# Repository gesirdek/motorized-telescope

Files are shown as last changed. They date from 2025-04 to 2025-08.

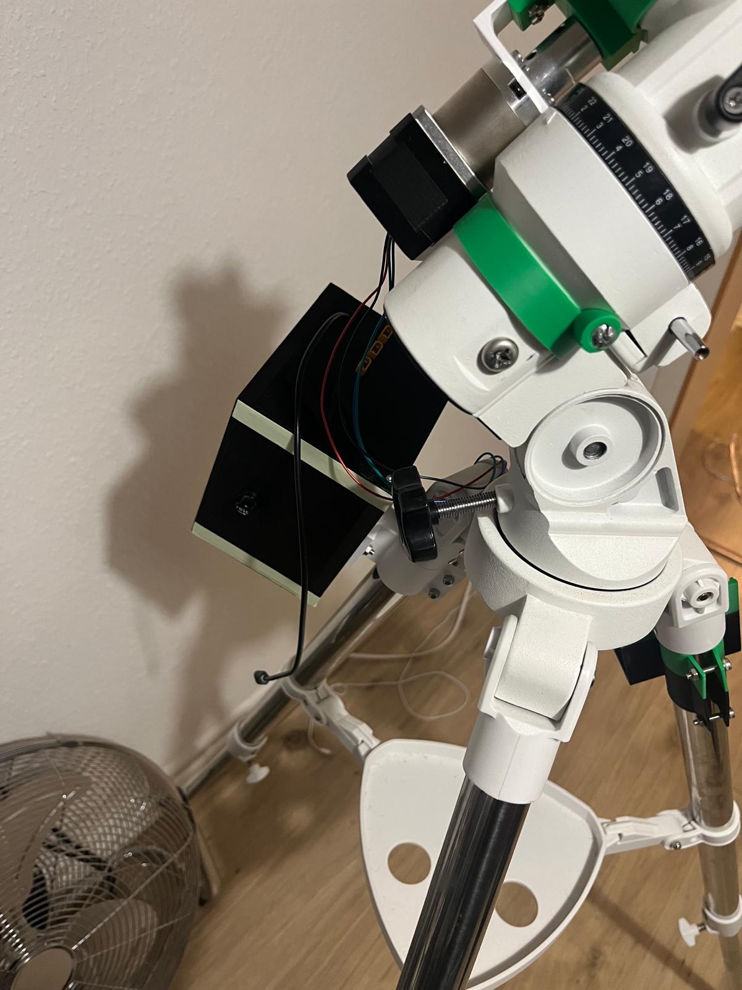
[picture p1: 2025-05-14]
photos/power-box-assembled.jpeg

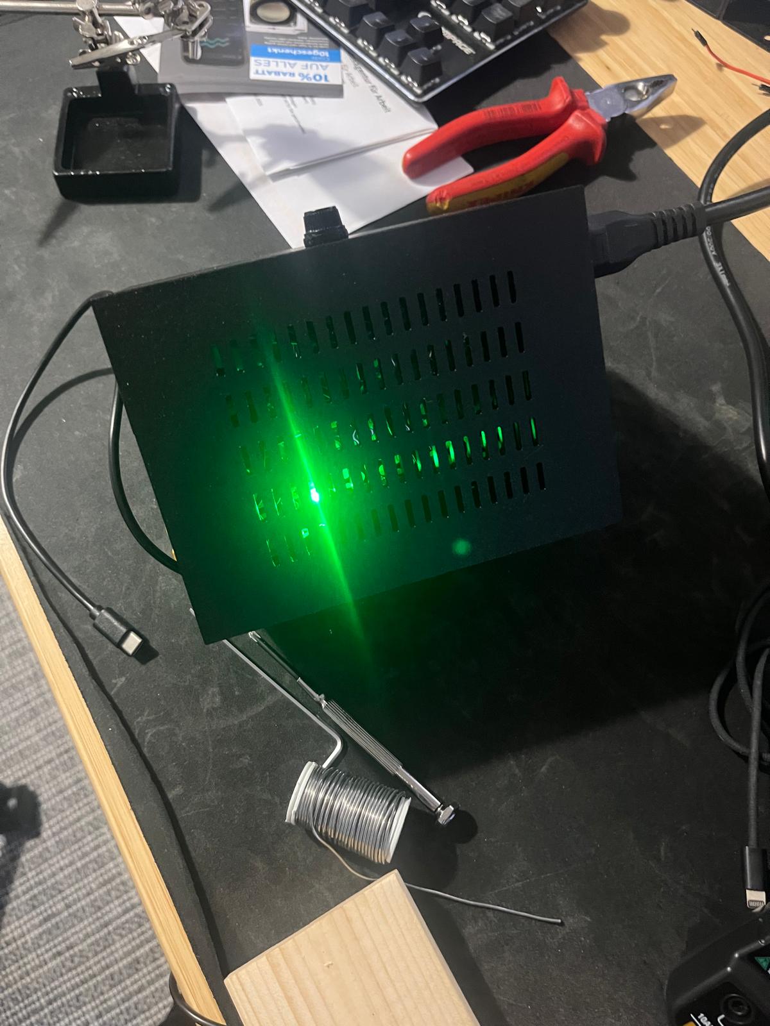
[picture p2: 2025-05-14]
photos/power-box-assembled-2.jpeg

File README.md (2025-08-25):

# Motorized Telescope

A fully motorized telescope project using 3D-printed parts, FreeCAD modeling, and ROS-based control system.  
The telescope uses an equatorial mount (Bresser AR102/1000) and will be upgraded with motors on the **Right Ascension (RA)**, **Declination (DEC)**, and **Focuser** axes for automatic tracking, alignment, and remote focusing.

This repository documents the full development process, including CAD models, electronics, motor control, ROS integration, and testing.

---

## 🚀 Project Goals

- ✅ Motorize **RA**, **DEC** axes using NEMA 17 planetary gear stepper motors.
- ✅ Motorize **Focuser** using 28BYJ-48 stepper motor.
- ✅ Design all mechanical parts in **FreeCAD** and prototype them with a **3D printer**.
- ✅ Control the motors via **stepper drivers (A4988 → TMC2209, ULN 2003)** and a **microcontroller (Arduino → D1 Mini)**.
- ✅ Use **ROS** for high-level control and coordination.
- ✅ Implement **GoTo & Tracking** based on celestial coordinates.
- ✅ Document all failed and revised prototypes to reduce material waste and improve design efficiency.
- ✅ Switched to **Raspberry Pi** for portable, self-contained operation.
- 🕒 Future plan - Support solar-powered operation for outdoor autonomy.

---

## ⚙️ Hardware Overview

| Component | Description |
|---|---|
| Telescope | Bresser AR102/1000, Equatorial Mount |
| Motors | NEMA 17 with Planetary Gear, 28BYJ-48 Step Motor  |
| Motor Drivers | NEMA 17 - A4988 (initial) → TMC2209 (planned), 28BYJ-48 - ULN 2003 |
| Microcontroller | D1 Mini (ESP8266) |
| Host Controller | Raspberry Pi 3 Model B+ |
| Power Supply | 12V 5A USB Adapter (later: solar panel) |
| 3D Printer | Bambu Lab P1P |

## 🛠️ Current Status

- [x] Repository initialized and documented
- [x] CAD measurements started, prototype V1 tested
- [x] Final RA motor mount design in progress
- [x] DEC mount modeling
- [x] Focuser gear mechanism prototyping
- [ ] ROS communication layer setup
- [ ] Integrated system test

---

## 📸 Photos & Prototyping Log

🗂️ Detailed iteration logs and photos are available in  
👉 [prototype-log.md](prototype-log.md)

## 📂 Repository Structure (Simplified)

- `cad/` → FreeCAD source file and STL files for 3D printing, and Bambu Studio `.3mf` project files
- `photos/` → Images of prototypes, failed prints, and final assemblies  
- `pcb/` → Gerber files and PCB resources for the motor control board
- `arduino/` → Microcontroller firmware for stepper drivers  
- `ros/` → ROS nodes for telescope control logic  
- `prototype-log.md` → Iteration notes, measurements, and learning from each step

## 📐 CAD Files

- All mechanical parts are designed in individual FreeCAD files.

- Each functional group (e.g. RA/DEC parts, power box) lives in its own folder under `/cad/`.

- Discarded or outdated parts are moved to a central file: [`TelescopeProject.FCStd`](cad/TelescopeProject.FCStd)

- Bodies that are no longer in use are marked with the suffix `_discarded`.  
  These represent either failed prints or designs that were intentionally replaced with better alternatives.

- STL files in `/cad/stl/` are **cleaned and curated**: they represent only the **most up-to-date and usable** versions of each part. 
- STL files in `/cad/stl/` follow the **same folder structure** as the FreeCAD source files.
- Discarded or outdated versions (which may have been printed previously) are **not included here**, but still exist as separate bodies in the FreeCAD source file

<details>
<summary>📁 CAD Folder Structure (click to expand)</summary>

```
/cad/
├── telescope_body_parts/
│ ├── DEC-Half-Pipe.FCStd
│ └── RA-Half-Pipe.FCStd
├── power-box-parts/
│ ├── Pin.FCStd
│ ├── Power-Box-Back.FCStd
│ ├── Power-Box-Base.FCStd
│ ├── Power-Box-Front.FCStd
│ ├── Power-Box-Left-Side.FCStd
│ ├── Power-Box-Right-Side.FCStd
│ └── Power-Box-Top.FCStd
├── ec-box-parts/
│ ├── EC-base.FCStd
│ ├── EC-Box-Assembly.FCStd
│ ├── EC-Box-Side-L.FCStd
│ ├── EC-Box-Side-R.FCStd
│ └── EC-Box-Top.FCStd
├── shared_parts/
│ ├──  L-Grabber.FCStd
│ └── TripodGrabber.FCStd
├── crayford_focuser/
│ ├── bearings-base.FCStd
│ ├── crayford-focuser-presser.FCStd
│ ├── crayford-holder.FCStd
│ └── crayford-tube.FCStd
├── stl/
│ ├── telescope_body_parts/
│ ├── power-box-parts/
│ ├── ec-box-parts/
│ ├── crayford_focuser/
│ └── shared_parts/
└── TelescopeProject.FCStd
```
</details>

## 🎛️ Bambu Studio Project Files

The `bambu-studio/` folder contains `.3mf` project files created with Bambu Studio. These files include both the 3D model(s) and all relevant print settings (such as layer height, speed, support configuration, and filament type) used for slicing.

Unlike some other slicers, Bambu Studio does not store print settings as separate configuration files — all settings are embedded within the `.3mf` file itself.

### Notes
- File names may indicate specific profiles (e.g., "high-quality", "draft", or nozzle size), but the actual configuration is always included in the `.3mf` file.
- If you're using a different slicer or printer, refer to the `.stl` files in the `stl/` folder and manually adjust your settings based on the intended configuration.
- Optional: some setting screenshots may also be included for reference.

## 🧩 PCB Files

Initial Gerber files for the motor control board are provided under `/pcb/gerber-files/`.

These are **v1 design files** and **have not yet been sent for PCB manufacturing**.  
Future versions may include design improvements based on testing results.

## ⚡ Power Supply Setup

The power supply consists of a ready-made 12V 5A unit mounted inside a protective enclosure.  
An inline T1A fuse (slow-blow) is installed on the AC input for safety, and a DC power distributor with integrated fuses is used to organize the 12V outputs.

No custom PCB is created for the power supply; connections are made manually using standard wiring.

## ⚠️ Disclaimer

This project involves work with high voltages (230V AC) and is provided as-is without any warranty.  
Use at your own risk. Ensure you have proper knowledge and take appropriate safety measures when replicating or modifying this system.

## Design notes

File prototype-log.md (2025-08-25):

# Prototyping & Iteration Log

This document records all 3D printed prototypes, their testing results, and learnings. Even failed or broken parts are documented to highlight design evolution and material efficiency.

---

## 📅 April 2025 — RA Half Pipe (First Attempt)

- **Goal**: Design a half-pipe mount to secure motor housing around the RA axis.
- **Result**: The piece cracked near the bolt hole. Instead of increasing wall thickness, I decided to extend the length of the half-circle so that the mounting holes would be easier to align and allow M5 screws to fit without stress.
- **Learning**: Geometric adjustments (e.g., part length) can sometimes be more effective than increasing thickness. This change also helped with assembly tolerance.
- 📸 `photos/RA-half-pipe-end-fail.jpeg`

---

## 📅 April 2025 — DEC Half Pipe (First Version)

- **Goal**: Create a symmetrical half-pipe bracket for the DEC axis mount.
- **Result**: Initial design printed correctly but cracked under bolt pressure.
- **Fix**: Strengthened the model with wider edge and offset the holes from edge.
- 📸 `photos/DEC-half-pipe-first-version.jpeg`
- 📸 `photos/DEC-Half-pipe-crack.jpeg`

---

## 📅 April 2025 — L-Bracket Motor Mounts (Comparison)

- **Goal**: Compare and test two L-bracket versions for mounting the NEMA17 planetary gear motor.
- **Result**: Both versions had compatible hole positions. However, the **left version was narrower**, which allowed correct positioning. The wider one did not leave enough clearance for the desired alignment.
- **Learning**: Bracket width matters for motor and coupling orientation — even if hole alignment is correct.
- 📸 `photos/nema17-L-bracket-2-versions-left-fits.jpeg`

---

## 📅 April 2025 — DEC Motor Mount (Mechanical Assembly Test)

- **Goal**: Assemble the DEC motor mount using the latest half-pipe version and L-bracket to test mechanical alignment and fit.
- **Result**: Mounting was mechanically successful. The motor aligned well with the coupling, and the bracket provided stable support. However, the DEC half-pipe still needs visual and geometric refinement for better fit and finish.
- **Next**: Perform motor test (rotation + holding torque) before proceeding to final cabling and driver installation.
- 📸 `photos/DEC-mount-succes-motor-L-connect.jpeg`
- 📸 `photos/DEC-mount-success-up.jpeg`
- 📸 `photos/DEC-coupling-motor-success.jpeg`

## 📅 April — RA Half Pipe V2 (Screw Alignment Issue)

- **Goal**: Redesign the RA half-pipe with a longer arc and improved screw hole alignment for M8 bolts.
- **Result**: The arc length was sufficient, but the screw hole geometry still didn't align properly with the mount holes. The piece couldn’t be mounted without excessive force.
- **Learning**: In the next version, precise measurement around the telescope collar and bolt spacing is required. Hole offset needs to be based on actual curvature path, not just diameter.
- 📸 `photos/RA-half-pipe-v2-failed-to-fit screw-2025-04-12 at 20.13.03.jpeg`

## 📅 April — RA Half-Pipe Adjustment Planning
- Slight increase in arc length (~3–5°) is required for better alignment of the motor arm.
- The M8 bolt hole needs a flared or curved entry for easier fitment, and slight sanding might be needed where the bracket meets the telescope.
- 📸 `photos/RA-half-pipe-adjustments-requıired-pipe-length.jpeg`, 
- 📸 `photos/RA-half-pipe-adjustments-requıired-screw.jpeg`

## 📅 April — RA Half Pipe Stable Version
- **Goal**: Produce a structurally stable RA half-pipe mount to carry the stepper motor.
- **Result**: The latest printed version successfully holds the motor with sufficient stability. Minor alignment refinements may still be required.
- 📸 `photos/14-04-2025-RA-half-pipe-stable_1.jpeg`,
- 📸 `photos/14-04-2025-RA-half-pipe-stable_2.jpeg`

## 📅 April — Updated L-Grabbers and Half-Pipe Mounts Installed
- **Goal**: Update L-grabbers and produce/install new half-pipe mounts for both RA and DEC motor setups.
- **Result**:Updated L-grabbers were successfully installed with revised half-pipe designs. Mounting alignment achieved with solid mechanical fit.
- 📸 `photos/L-Grabber-mounted-1.jpeg`,
- 📸 `photos/L-Grabber-mounted-2.jpeg`,
- 📸 `photos/L-Grabber-mounted-3.jpeg`

## 📅 April — First Motor Spin with D1 Mini
- **Goal**:  Verify stepper motor movement using D1 Mini and initial breadboarded electronics.
- **Result**: Successfully controlled one stepper motor via D1 Mini using STEP/DIR pins. Stable rotation achieved.
- 📸 `photos/Stepper-Motor-1.jpeg`,
- 📸 `photos/Stepper-Motor-E.jpeg`,
- 📸 `photos/Elect-Stepper-Motor.png`

## 📅 April 24, 2025 — Electronics Enclosure Design Started
- **Goal**: Begin designing a housing/enclosure for the electronics, including the D1 Mini and driver boards.
- **Result**:  Initial sketches and measurements completed. Enclosure will accommodate future upgrades. Next goal: drive two motors via a single D1 Mini.
- 📸 `photos/Elect-Box-1.png`
- 📸 `photos/Elect-Box-2.png`

## 📅 May 6, 2025 — Power Supply Enclosure Design in Progress
- **Goal**: Create a stable and compact enclosure to house the power supply and related wiring.
- **Result**:  Preliminary design completed in FreeCAD. Dimensions adjusted to fit under telescope tripod. Ventilation and cable routing considered.
- 📸 `photos/PETG-power-supply-fail.png`
- 📸 `photos/PETG-power-supply-fail-2.png`

## 📅 May 8, 2025 — Power Box Assembly Test (Right, Rear, Base)
- **Goal**: Print and test-fit the right, rear, and base parts of the power supply box.
- **Result**: Parts interlocked successfully. Some minor issues occurred.
- 📝 Forgot to include one of the holes on the rear panel — drilled manually.
- 📝 The lower interlock on the right side was printed with support; removal left a rough surface.
- 📝 Didn't sand the surface; assembly required some force but was possible.
- 📝 Fit was not smooth; alternative support strategy needed for future prints.
- 📸 `photos/power-box-fit-test-2025-05-08.png`
- 📸 `photos/power-box-back.jpeg`
- 📸 `photos/power-box-base-back-right.jpeg`
- 📸 `photos/power-box-right-panel.jpeg`

## 📅 May 14, 2025 — Power Box Final Assembly and Verification
- **Goal**: Complete assembly of the power supply box and perform final verification.
- **Result**: Assembly completed successfully. Output stable under load.
- 📝 All panels fully assembled and interlocked.
- 📝 Fluorescent tape applied to edges for visibility in low light.
- 📝 Hot glue used to secure internal components.
- 📝 Output voltage and current tested — stable operation confirmed.
- 📝 No overheating or noise detected during test.
- 📸 photos/power-box-assembled.jpeg
- 📸 photos/power-box-assembled-2.jpeg
- 📸 photos/power-box-internal-hotglue.jpeg
- 📸 photos/power-box-fluorescent-edges.jpeg

## 📅 May 21, 2025 — RA/DEC Motor Box Assembly and Test
- **Goal**: Assemble the RA/DEC control box, wire the electronics, and verify functionality via MQTT.
- **Result**: System operational; motors respond correctly to MQTT commands.
- 📝 RA/DEC box assembled and electronics placed inside.
- 📝 All internal wiring completed; connections verified.
- 📝 One faulty Dupont cable was replaced.
- 📝 Box closed and system tested.
- 📝 After powering D1 Mini and sending MQTT command via Mosquitto, both RA and DEC motors moved as expected.
- 📝 Noticed that motor power must be connected after D1 Mini is powered on — this behavior needs investigation.
- 📝 Planned task completed: Structured Wi-Fi command interface implemented using MQTT; remote control now functional.
- 📽️ [Watch test video on YouTube](https://youtube.com/shorts/sel-l1Y8c-Y)

## 📅 May 21, 2025 — Motor Power Sequencing Issue: Solution Identified
- **Goal**: Investigate why motors must be powered only after D1 Mini boot.
- **Result**: Root cause identified; hardware solution planned but not yet implemented.
- 📝 Observed issue: system only works if motor power is connected after D1 Mini is booted.
- 📝 Suspected power sequencing conflict between D1 Mini and motor drivers.
- 📝 Proposed solution: add IRLZ44N N-channel MOSFET to control motor GND via GPIO.
- 📝 D1 Mini would enable motor power after it completes boot sequence.
- 📝 330Ω resistor and optional 10kΩ pull-down recommended for stable gate control.
- 📝 Implementation pending — to be tested in upcoming iteration.
- 📝 Gerber files will need to be updated if solution is verified.

## 📅 June 08, 2025 — Crayford Focuser Design Initiated
- **Goal**: Begin designing a Crayford-style focuser with stepper motor integration.
- **Result**: Initial design concepts completed; parts adapted to motor and shaft geometry.
- 📝 Started working on focuser motor design; aiming to build a Crayford focuser.
- 📝 Creating a design that allows mounting a 28BYJ-48 stepper motor.
- 📝 Planning to reuse a shaft from an old toy car wheel as the drive axle.
- 📝 Updated current designs to accommodate the reused shaft.

## 📅 June 20, 2025 — Crayford Focuser Mechanism Assembled and Tested
- **Goal**: Complete physical assembly of the Crayford focuser and verify mechanical operation.
- **Result**: Assembly completed successfully; mechanical movement confirmed; initial driver circuit test passed.
- 📝 Crayford focuser mechanism fully assembled and manually tested.
- 📝 Basic physical operation appears normal; no major resistance or misalignment observed.
- 📝 This test only covered manual operation, motor-driven behavior on the focuser itself still untested.
- 📝 Switched to a metal coupling for the drive axle, which improved mechanical consistency and alignment.
- 📝 Stepper motor and driver circuit tested separately — motor responds correctly.

## 📅 August 20, 2025 — Crayford Focuser Motor Test & MQTT Communication

**Goal**: Move the Crayford focuser with a motor and verify MQTT communication.
**Result**: The initial motor test failed; the motor could not turn the focuser due to insufficient clearance. Adding a spring solved the clearance issue, and the motor was able to move the focuser successfully.
**MQTT Test**: Communication tests with an MQTT broker on Ubuntu were successful. Commands were transmitted correctly and the system responded as expected.
**Learning**: For efficient motor operation in the Crayford focuser mechanism, spring-based clearance adjustment is critical. Remote control via MQTT works reliably.

## 📅 August 25, 2025 — MQTT Broker Migration to Raspberry Pi & System Test

**Goal**: Migrate the MQTT broker from Ubuntu to Raspberry Pi 3B+ and repeat the focuser motor test.
**Setup**: Used a Raspberry Pi 3B+ (32-bit OS for better performance and compatibility with camera and MQTT). The system boots from a USB stick to utilize available resources.
**Result**: The MQTT broker runs smoothly on the Raspberry Pi, and the focuser motor test was successful. Performance is currently satisfactory.
**Next Steps**: Plan to add a camera and retest. Depending on camera performance, may upgrade hardware or keep the current setup.
**Learning**: Migrating the broker to Raspberry Pi is practical and efficient for this project. USB boot and 32-bit OS provide enough performance for MQTT and camera tasks with available hardware.

🛠️ Planned: 
- Gerber file needs to be updated to reflect latest wiring and component layout.

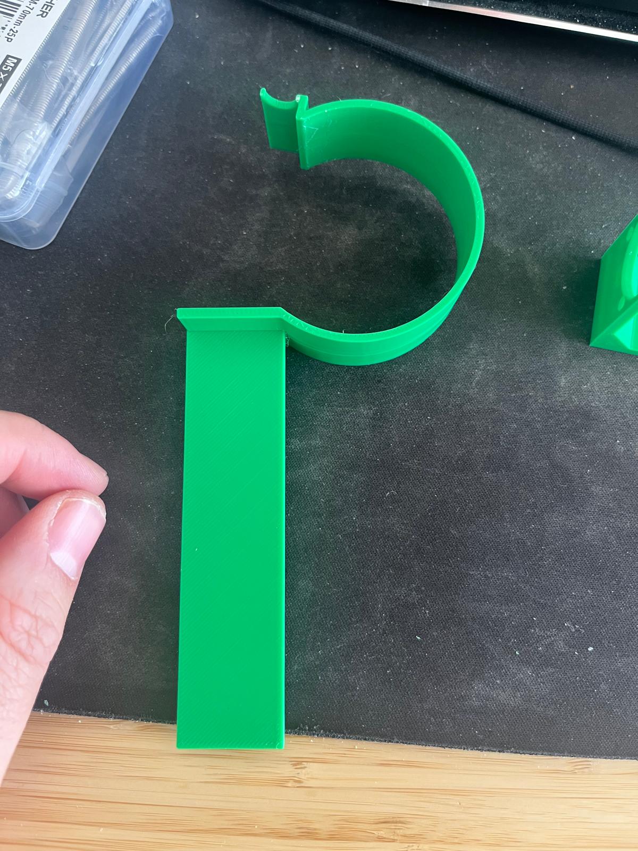
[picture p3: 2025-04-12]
photos/RA-half-pipe-end-fail.jpeg

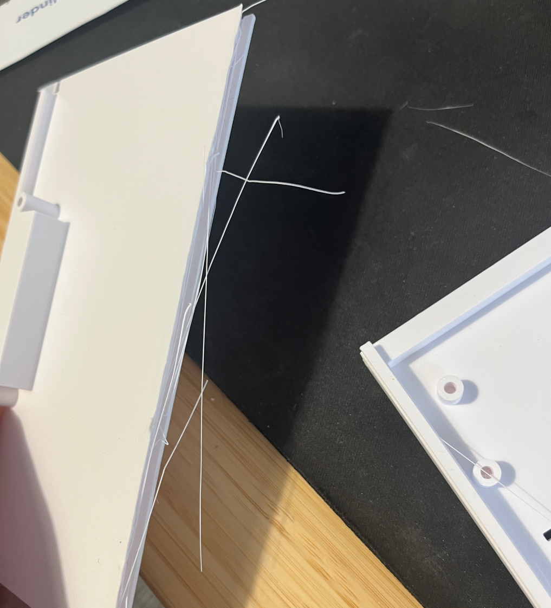
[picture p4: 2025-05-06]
photos/PETG-power-supply-fail-2.png

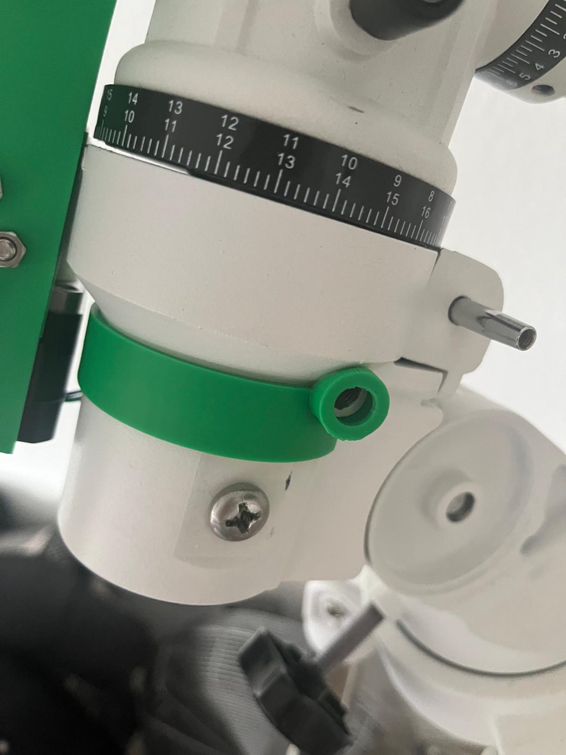
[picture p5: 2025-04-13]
photos/RA-half-pipe-adjustments-requıired-screw.jpeg

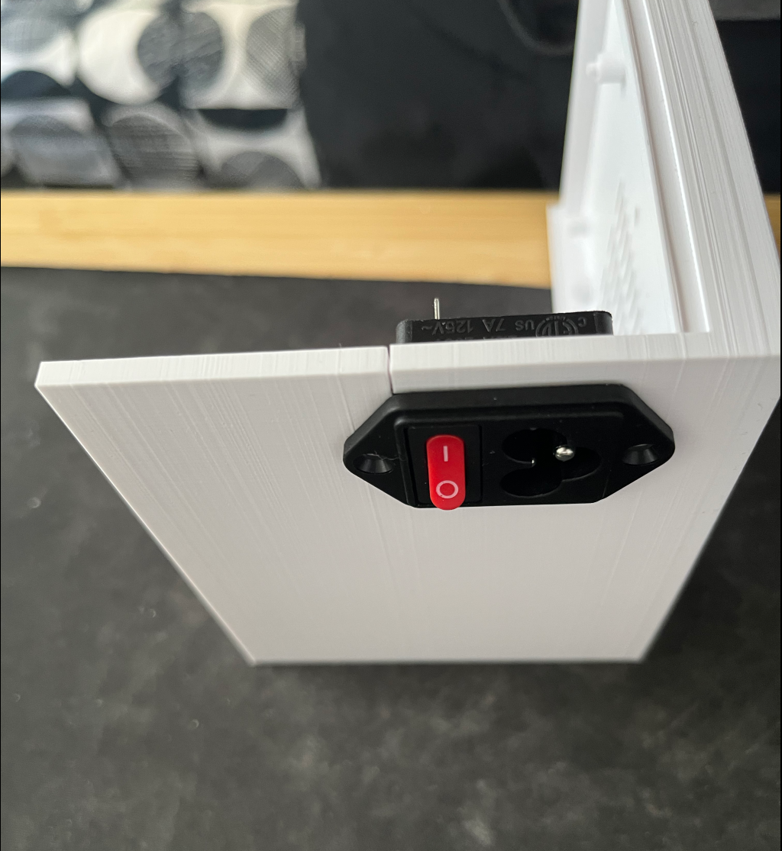
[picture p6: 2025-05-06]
photos/PETG-power-supply-fail.png

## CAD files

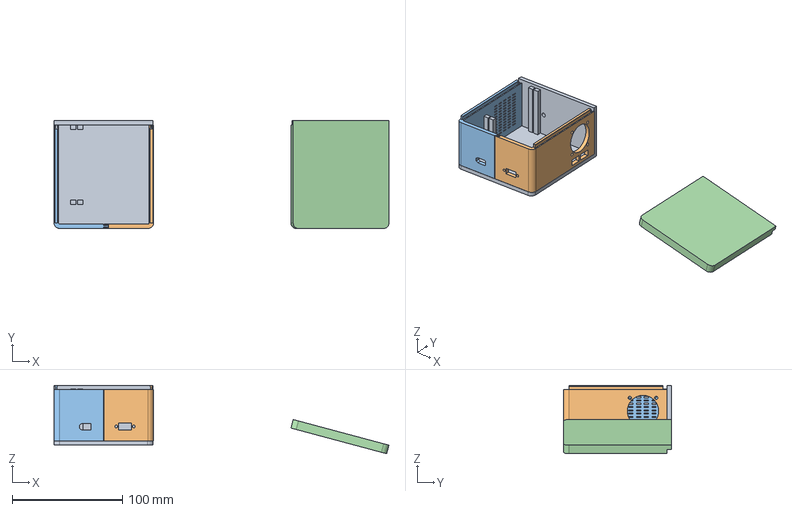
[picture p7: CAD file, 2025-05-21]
cad/ec-box-parts/EC-Box-Assembly.FCStd
304.0 x 98.0 x 62.1 mm
EC-Base_001
EC-Box-Side-R_001
EC-Box-Side-L_001
EC-Box-Top_001

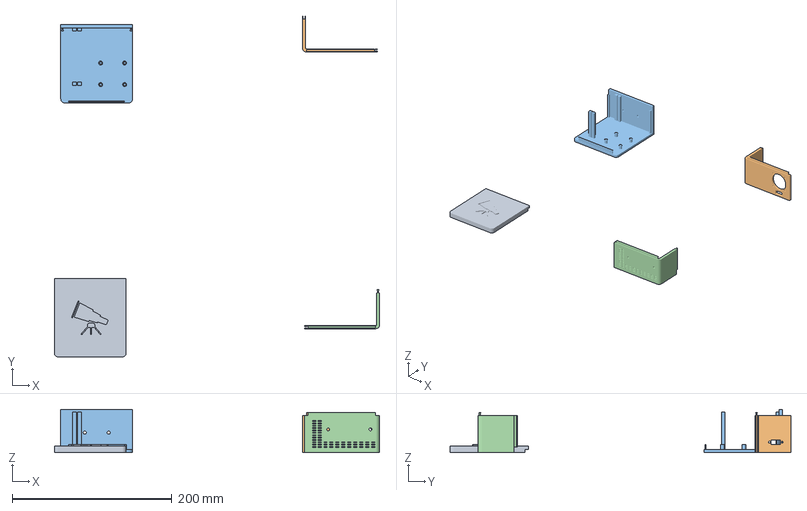
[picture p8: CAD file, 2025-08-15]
cad/bambu-studio/focuser-box.3mf
407.2 x 426.8 x 54.0 mm
focuser-box-top.stl
focuser-box-side-r-fb-side-r.stl
focuser-box-base-fb-base-part.stl
focuser-box-side-l-fb-side-l.stl

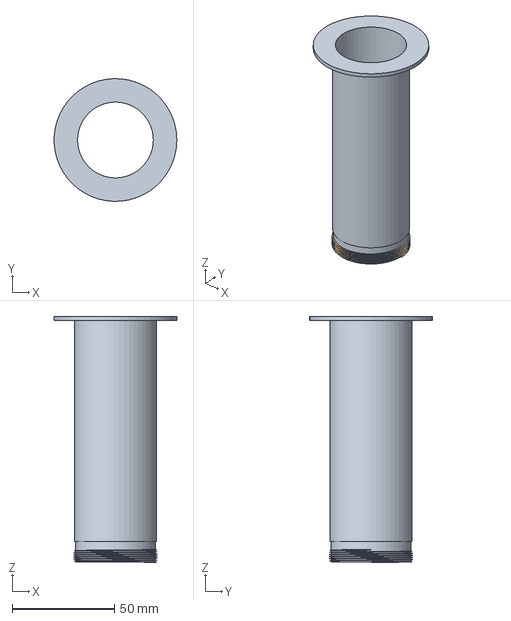
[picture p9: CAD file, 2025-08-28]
cad/crayford-focuser/crayford-tube.FCStd
59.9 x 60.0 x 120.2 mm
crayford-tube

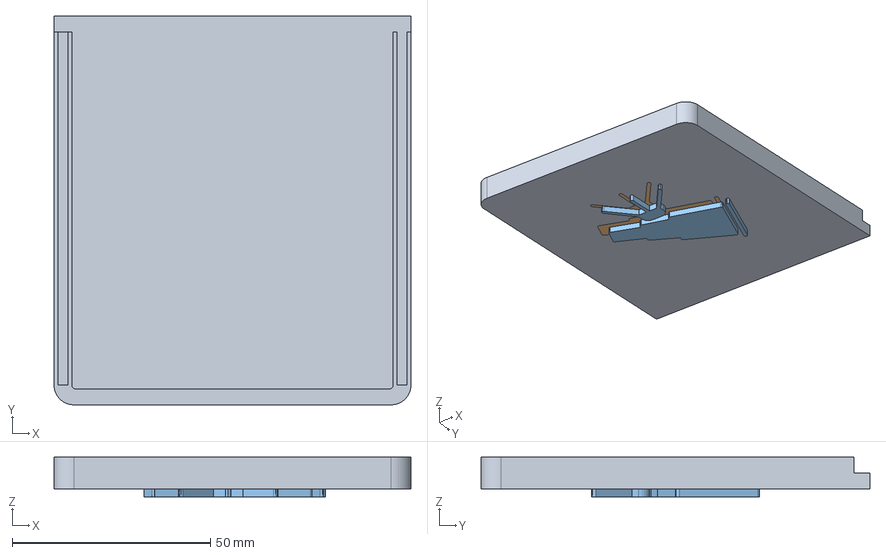
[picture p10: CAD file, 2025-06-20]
cad/ec-box-parts/EC-Box-Top.FCStd
90.0 x 98.0 x 10.0 mm
Ec-Box-Top

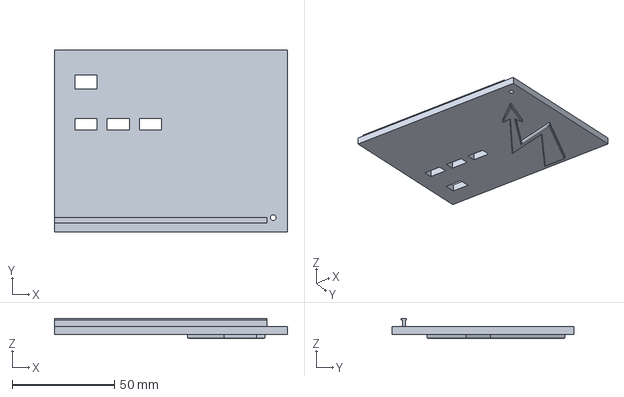
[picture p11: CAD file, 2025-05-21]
cad/power-box-parts/Power-Box-Front.FCStd
114.0 x 89.0 x 9.90 mm

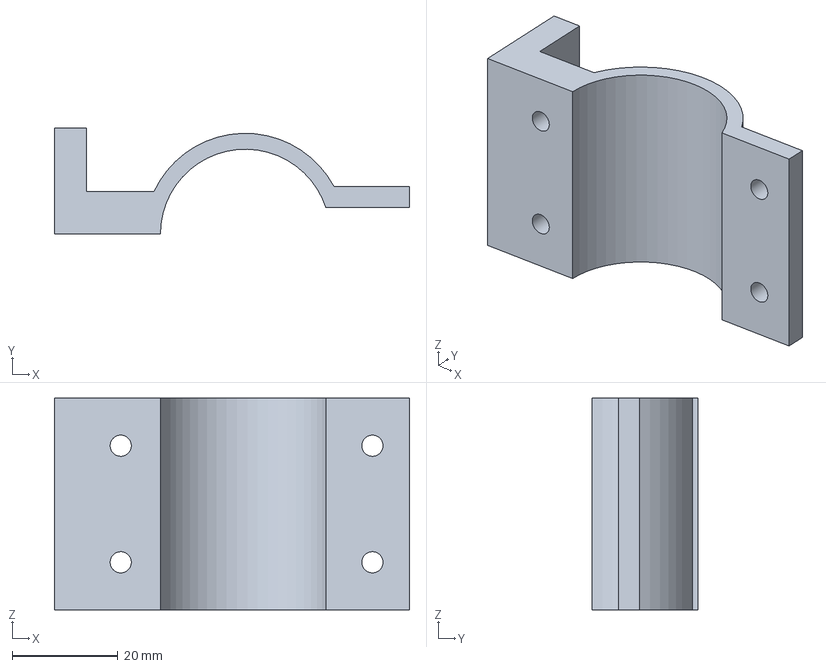
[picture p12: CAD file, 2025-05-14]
cad/shared-parts/TripodGrabber.FCStd
67.0 x 20.0 x 40.0 mm

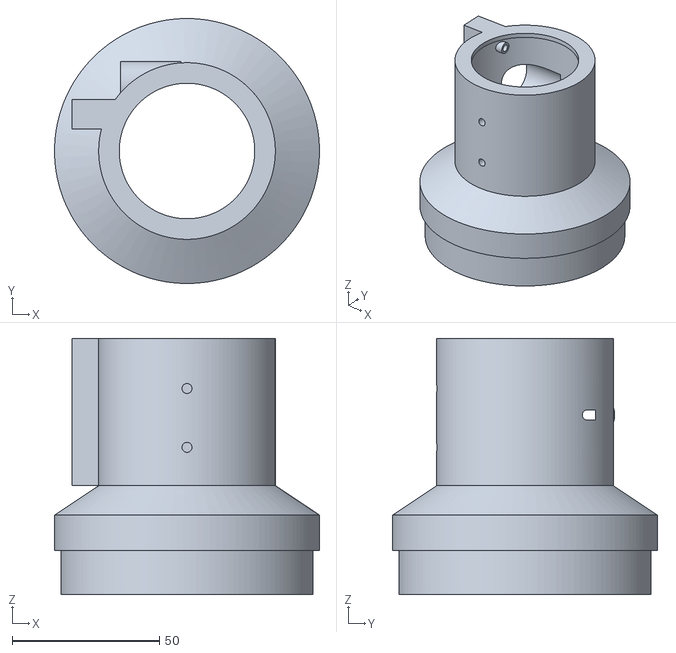
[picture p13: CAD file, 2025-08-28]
cad/stl/crayford-focuser/crayford-holder-crayford-holder.stl
90.0 x 90.0 x 87.0

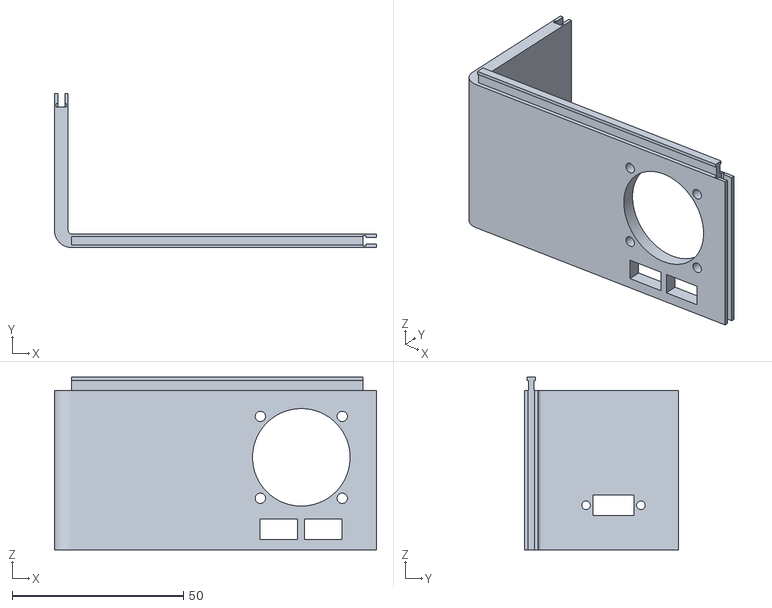
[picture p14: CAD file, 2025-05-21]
cad/stl/ec-box-parts/EC-Box-Side-R-EC-Box-Side-R.stl
94.0 x 45.0 x 50.4

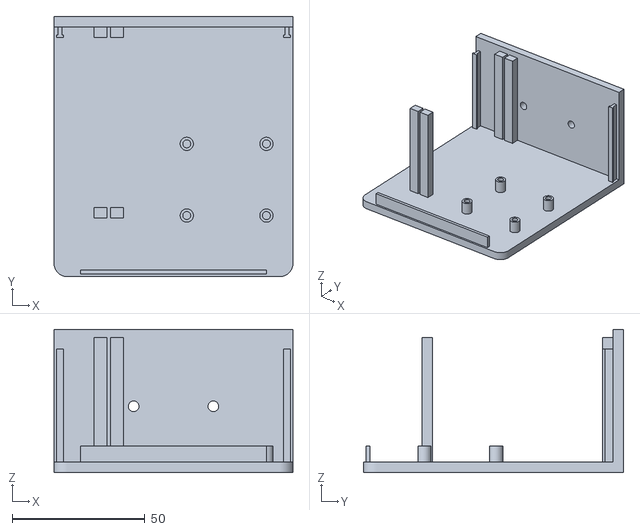
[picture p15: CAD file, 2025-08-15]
cad/stl/focuser-box-parts/focuser-box-base-fb-base-part.stl
90.0 x 98.0 x 54.0

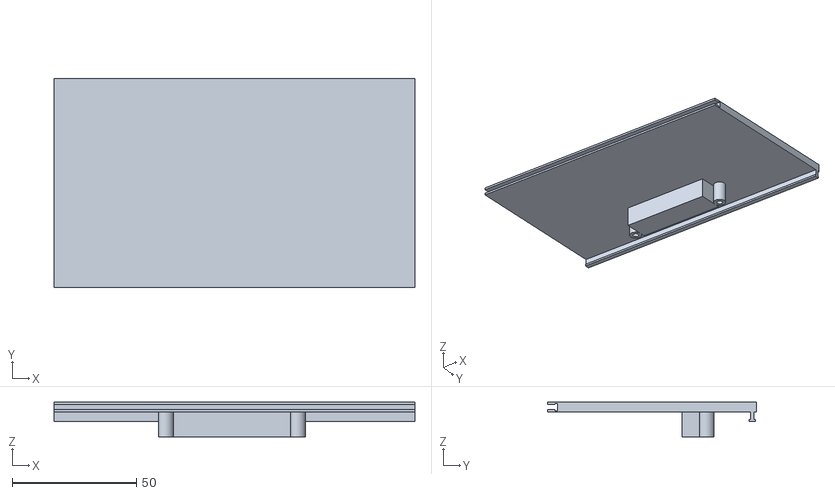
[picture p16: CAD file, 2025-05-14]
cad/stl/power-box-parts/Power-Box-Right-Side-Power-Box-R.stl
145.0 x 84.0 x 14.0

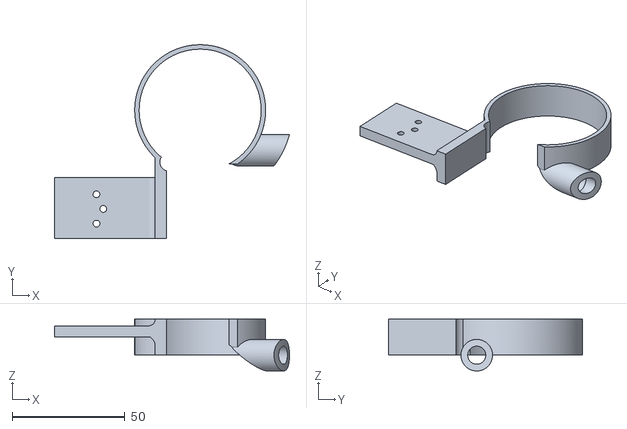
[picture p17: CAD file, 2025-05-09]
cad/stl/telescope-body-parts/RA-Half-Pipe-RA-Half-Pipe.stl
104.1 x 85.8 x 23.0

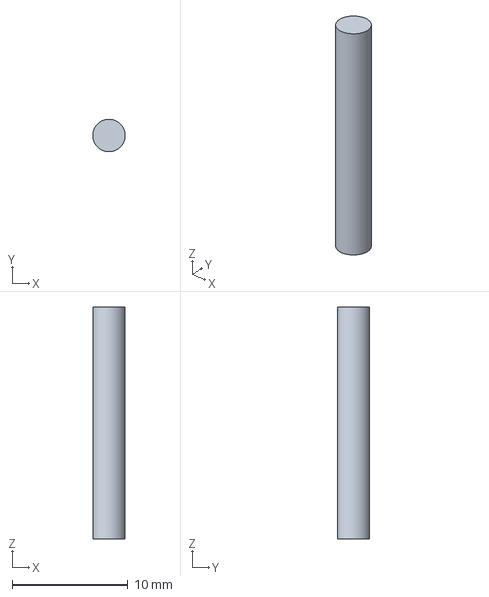
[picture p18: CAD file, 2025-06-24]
cad/TelescopeProject.FCStd
2.80 x 2.80 x 20.0 mm

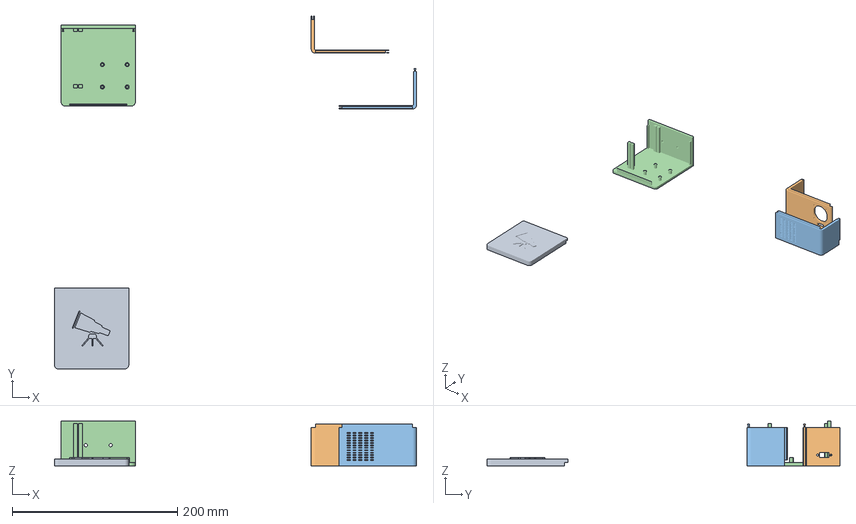
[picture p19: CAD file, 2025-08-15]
cad/bambu-studio/focuser-box-top.3mf
438.0 x 426.8 x 54.0 mm
focuser-box-top.stl
focuser-box-side-r-fb-side-r.stl
focuser-box-side-l-fb-side-l.stl
focuser-box-base-fb-base-part.stl

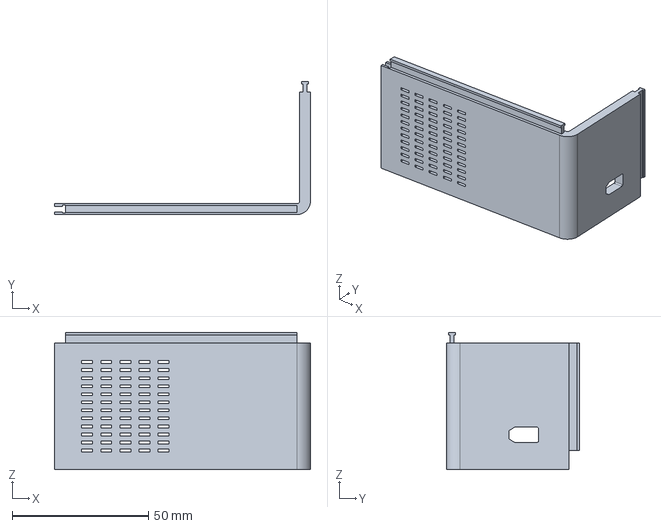
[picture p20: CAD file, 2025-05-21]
cad/ec-box-parts/EC-Box-Side-L.FCStd
94.0 x 48.9 x 50.4 mm

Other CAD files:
cad/stl/Power-Box-Assembly.FCStd
cad/focuser-box-parts/focuser-box-top.FCStd
cad/telescope-body-parts/RA-Half-Pipe.FCStd
cad/crayford-focuser/crayford-holder.FCStd
cad/bambu-studio/TelescopProject-PowerBox.3mf
cad/bambu-studio/TelescopProject-RaDecBox.3mf
cad/bambu-studio/TelescopeProject-CrayfordFocuser.3mf
cad/crayford-focuser/bearings-base.FCStd
cad/crayford-focuser/crayford-focuser-coupling_discarded.FCStd
cad/crayford-focuser/crayford-focuser-presser.FCStd
cad/ec-box-parts/EC-Base.FCStd
cad/ec-box-parts/EC-Box-Side-R.FCStd
cad/focuser-box-parts/focuser-box-base.FCStd
cad/focuser-box-parts/focuser-box-side-l.FCStd
cad/focuser-box-parts/focuser-box-side-r.FCStd
cad/power-box-parts/Pin.FCStd
cad/power-box-parts/Power-Box-Back.FCStd
cad/power-box-parts/Power-Box-Base.FCStd
cad/power-box-parts/Power-Box-Left-Side.FCStd
cad/power-box-parts/Power-Box-Right-Side.FCStd
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

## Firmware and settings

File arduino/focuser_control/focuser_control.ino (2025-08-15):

#include <ESP8266WiFi.h>
#include <ArduinoOTA.h>
#include <PubSubClient.h>

#include "secrets.h"   // WiFi & MQTT credentials
#include "Motor.h" // Motor class
#include "mqtt.h"      // MQTT logic

// Global hardware and state instances
WiFiClient espClient;
PubSubClient client(espClient);

Motor fMotor(14, 12, 13, 15);

bool isBusy = false;
bool isStopped = false;

void setup() {
  Serial.begin(115200);
  pinMode(FAN_PIN, OUTPUT);
  digitalWrite(FAN_PIN, LOW); // Fan is off
  // Connect to Wi-Fi
  WiFi.begin(WIFI_SSID, WIFI_PASS);
  while (WiFi.waitForConnectResult() != WL_CONNECTED) {
    delay(1000);
    ESP.restart();
  }

  // Enable OTA
  ArduinoOTA.setHostname(OTA_FOCUSER_HOST);
  ArduinoOTA.setPassword(OTA_FOCUSER_PASS);
  ArduinoOTA.begin();

  // Setup MQTT
  client.setServer(MQTT_HOST, 1883);
  client.setCallback(mqttCallback);

  reconnectMQTT("FocuserClient", "focuser/komut"); // Subscribe to topics
}

void loop() {
  ArduinoOTA.handle();

  if (!client.connected()) {
    reconnectMQTT("FocuserClient", "focuser/komut");
  }

  client.loop();
}

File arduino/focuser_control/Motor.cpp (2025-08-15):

#include "Motor.h"

Motor::Motor(int in1, int in2, int in3, int in4)
  : _in1(in1), _in2(in2), _in3(in3), _in4(in4), _stepIndex(0) {
  pinMode(_in1, OUTPUT);
  pinMode(_in2, OUTPUT);
  pinMode(_in3, OUTPUT);
  pinMode(_in4, OUTPUT);
  stop();
}

// 8-step half-stepping sequence
void Motor::step(int index) {
  static const bool steps[8][4] = {
    {1, 0, 0, 0},
    {1, 1, 0, 0},
    {0, 1, 0, 0},
    {0, 1, 1, 0},
    {0, 0, 1, 0},
    {0, 0, 1, 1},
    {0, 0, 0, 1},
    {1, 0, 0, 1}
  };

  digitalWrite(_in1, steps[index][0]);
  digitalWrite(_in2, steps[index][1]);
  digitalWrite(_in3, steps[index][2]);
  digitalWrite(_in4, steps[index][3]);
}

void Motor::stepForward(int steps) {
  for (int i = 0; i < steps; ++i) {
    _stepIndex = (_stepIndex + 1) % 8;
    step(_stepIndex);
    delay(2);
  }
}

void Motor::stepBackward(int steps) {
  for (int i = 0; i < steps; ++i) {
    _stepIndex = (_stepIndex + 7) % 8; // -1 % 8 = 7
    step(_stepIndex);
    delay(2);
  }
}

void Motor::stop() {
  digitalWrite(_in1, LOW);
  digitalWrite(_in2, LOW);
  digitalWrite(_in3, LOW);
  digitalWrite(_in4, LOW);
}

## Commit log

2025-04-12 inital updates
    [TelescopProject-DEC-Pipe-Holes.stl, TelescopProject-L-Grabber.stl, TelescopProject-RA-Pipe-Holes.stl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]
2025-04-13 CAD: RA pipe adjustments
    [TelescopProject-RA-Pipe-Holes.stl, TelescopProject.FCStd]
2025-04-14 CAD: RA pipe stable version
    [TelescopProject-RA-Pipe-Holes.stl, TelescopProject.FCStd]
2025-04-24 readme updates, cad updates
    [TelescopProject-DEC-Pipe-Holes.stl, TelescopProject-Focuser-Coupling.stl, TelescopProject-L-Grabber-DEC.stl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]
2025-04-29 arduino motor control, cad updates, initial gerber files, update readme
    [TelescopProject-RA-Box-bottom.stl, TelescopProject.FCStd]
2025-05-06 update cad files, add prototype log
    [TelescopProject-L-Grabber.stl, TelescopProject-Power-Box-Base.stl, TelescopProject-Power-Box-Front.stl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]
2025-05-07 update cad files
    [TelescopProject-Pin.stl, TelescopProject-Power-Box-Back.stl, TelescopProject-Power-Box-Base.stl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]
2025-05-07 update power box back
    [TelescopProject-Power-Box-Back.stl, TelescopProject-Tripod-Grabber.stl, TelescopProject.FCStd]
2025-05-09 organized stl and cad files, update readme file, add log
    [DEC-Half-Pipe-DEC-Half-Pipe.stl, DEC-Half-Pipe.FCStd, EC-Box-Bottom-EC-Box-bottom.stl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]
2025-05-09 organize stl folder, update readme
    [TelescopeProject.FCStd]
2025-05-14 update cad files, update logs
    [EC-Base-EC-Base.stl, EC-Base.FCStd, EC-Box-Bottom-EC-Box-bottom.stl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]
2025-05-21 create assembly for ec-box, update cad files, update log, update D1 mini code
    [EC-Base-EC-Base.stl, EC-Base.FCStd, EC-Box-Assembly.FCStd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]
2025-06-20 crayford focuser design updated
    [EC-Box-Top.FCStd, Power-Box-Assembly.FCStd, TelescopeProject-CrayfordFocuser.3mf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]
2025-06-24 update README file, update unused cad design name
    [TelescopeProject.FCStd]
2025-06-24 update README file
    [focuser-box-base.FCStd, focuser-box-side-l.FCStd, focuser-box-side-r.FCStd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]
2025-08-15 focuser updates
    [TelescopeProject-CrayfordFocuser.3mf, crayford-holder-crayford-holder.stl, crayford-holder.FCStd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]
2025-08-20 cad update
    [bearings-base-crayford-bearing-base.stl, bearings-base.FCStd]
2025-08-28 focuser motor delay increased
2025-08-28 bearing input modified
    [bearings-base-crayford-bearing-base.stl, bearings-base.FCStd]
2025-08-28 update focuser design and motor code.
    [bearings-base.FCStd, crayford-holder-crayford-holder.stl, crayford-holder.FCStd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]
2026-02-10 latest cad updates
